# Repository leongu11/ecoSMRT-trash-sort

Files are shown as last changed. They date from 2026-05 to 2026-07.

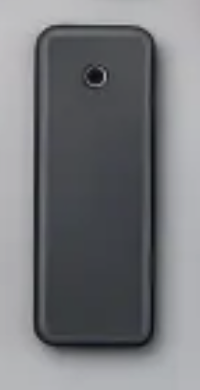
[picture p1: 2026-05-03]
SMRTcan-dataset/nonrecycling/box.jpg

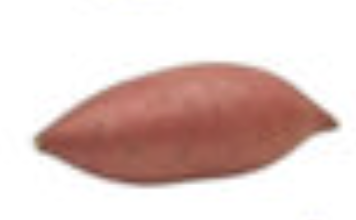
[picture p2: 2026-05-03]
SMRTcan-dataset/nonrecycling/fart.jpg

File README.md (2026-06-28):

github-header-banner

# ecoSMRT



## Overview
(this is my second README for this project -- I accidentally deleted the first one)
ecoSMRT is an edge AI project which determines if an article of trash is a recyclable (bottle) or not and sorts it accordingly.
It uses a refined version of MobileNetV2's CNN (convolutional neural networks) specifically for this task to make quality inferences. The model is around 60-70% accuracy when it comes to strong confidences over the 90% threshold.
I have logged nearly 45+ hours working on ecoSMRT as part of Hackclub's program, STASIS. Journal entries after every work session are also posted on the repository. 

## Incentive
Often times, managing waste can be overwhelming and done incorrectly. At the recycling level, nearly 76% of recyclables are lost at the household level (https://recyclingpartnership.org/residential-recycling-report/), and even those which are put into the recycling bin can be wrongly classified. As these wrongly-sorted articles of trash add up, the recycling process loses its efficiency, inflating unnecessary costs to over $3.5 billion yearly for the US (https://www.federalrecycling.com/industry-insights/common-recycling-mistakes-and-how-to-avoid-them/). As a direct result, recycling becomes more of a burden than a tool. Human error is exacerbating what recycling aims to fix: bettering the environment. Instead of looking towards refining the system, we should look to fix the root of the cause, our inaccuracies, by removing ourselves from the equation. AI is better than humans probably so like make a trash sorter ig 🤷‍♂️.

## Assembly Instructions
Use .stl files to print all 3d parts -- this includes the lid, the two edge mount pieces, the servo-lid adapter piece, and the camera mount (which is fixed to one of the edge mounts). NOTE: THE SERVO-LID ADAPTER PIECE REQUIRES A PAUSE IN THE PRINT TO SNAP ON THE HORN IN ORDER TO SEAL IT INSIDE THE PRINT! Slide the lid between the mounts to fix it in the center of the bin. Fasten the servo to the edge mount with two servo horn screws (which should have come with the servo) and connect the servo-lid adapter with the horn inside to the servo. Connect the adapter and the lid's extensions together-- glue is reccomended. The lid should now not rotate freely and rotating it should turn the servo, too. Attach a usb-c to usb-c onto the esp32 and camera and tape/glue to the top of the mount, allowing the camera to rest on the side of the mount. Connect the usb-c and flash the test-camera sketch onto the Xiao. It should return an IP to visit on the web to check the positioning of the camera. Adjust accordingly in order to have a clear view of the center of the bin. Using three jumper wires, solder the ends to both a capacitor and diode (optional, but recommended) using the schematic as a guide. Connect these jumpers to the servo, matching the power, ground, and signal accordingly. Once complete, flash the ecoSMRT-code onto the xiao. You should see inferences in the serial monitor and the lid rotating when those inferences pass the .95 -- or 95% -- threshold. Use the usb-c to power with any wall plug adapter or even laptop. 

## How ecoSMRT was made
I had originally settled for a more complex mechanical sorter, but the AI proved to be a challenge, so I simplified its design down to focus on firmware. The AI and curating a dataset which could yield decent results was also hard: At first, I was taking pre-existing datasets online, but the models were terrible. I did a lot of research and realized that I should probably use the native camera and setup for the training data, which turned out to work much better. Also, I switched from FOMO to MobileNet because like a month in I realized that image detection and classification were completely different (explanation found in journal). Everything else was relatively smooth sailing.

## Bill of Materials
| Component | Description | Cost | Link | 
|---|---|---|---|
| XIAO ESP32S3 Sense | Microcontroller with camera | $23.99 | [link](https://www.amazon.com/gp/product/B0CNL755KP/ref=ox_sc_act_title_2?smid=A2QTZX14X1D97I&th=1)
| MG90 servo | Sorting | $8.88 | [link](https://www.amazon.com/Seeed-Studio-XIAO-ESP32-Sense/dp/B0C69FFVHH?th=1)
## Hardware 
- MCU - Xiao ESP32S3-Sense w/ built-in camera module:
The Xiao ESP32 felt like the suitable choice because of its dual-core processors and built-in camera, which allowed the classification model to run smoothly locally, along with its GPIO capabilities.
Camera - OV2640 
- MG90 Microservo:
I have had my fair share of bad experience with the SG90 on multiple accounts, so I opted for its counterpart with metal-geared teeth, which seemed to be a good idea for tourque.

## Electronic Framework
I designed a schematic and PCB for this project in KiCAD

Schematic for wiring on perfboard:



PCB: 




I plan to use a perfboard using these as references for the physical project. 

## CAD / 3d Printed Parts
SMRTCAN--exploded2

Parts are printed in PLA, amounting to around 300 grams of filament (although all my prototypes summed up to a kg spool)
These consist of the bin's lid, which revolves on small axis extensions. These pass through bores that connect to the edges of the lid, and, when connected to the servo, keep the lid at the set position. The mount for the ESP32 slides around the servo's housing and attach to its walls. Additionally, I have modeled small attachments to connect the two halves of the lid if it cannot be printed as one part. 

## Software & Dependencies
- Arduino IDE
- Edge Impulse CLI
- ESP32 Arduino Core 2.0.8+
- `bottleclassifications_inferencing` (included in `/lib`) (refined w/ Edge Impulse)
- servo/webserver libraries used for testing/deployment
  
here are some crappy inferences from my first few models:



### Image Classification VS Object Detection (written in a journal entry)
Classification observes the image as a whole and returns a confidence score; its only question to ask is: What is this thing in front of me? Detection has to decide three things: Are there multiple objects? What are the objects? Where are the objects? In this case, the model has to consider spatial data when moving forwards for its confidence, which takes a lot more computing power and is way too overkill for my project.

### How Image Classification Works
Image classification is tuning a pre-trained model for a specific need. My model, MobileNetV2 has already been trained on ImageNet with millions of classification data – its weights have already adjusted to finding curves, textures, and colors within an image. What the refining does is simply re-run these weights over the image (or vector with the image data) – there is a series of these filters (matricies which are averaged out to make smaller maps) that alter the feature map that compound on one another, so they take the last feature’s map, instead of the old image. In this way the filters are able to distinguish curves, then textures, then shapes, then the image itself – again stacking over itself. The result is a confidence score that can be achieved even with little data.

## Dataset
- Trained on [Edge Impulse](https://edgeimpulse.com)

## How It Works & Usage
Frames are fed into the CNN, which returns inferences for classifications in real time. If an inference exceeds the 90% confidence threshold, the servo adjusts lid in one direction or another, 'sorting' the article of trash. 

To use, place the trash on the lid in front of the camera and in any orientation and wait for the bin to sort before placing the second article of trash down. 

## Future Improvements
- Improving vision model by manually training on pytorch or by expanding dataset
- adding feet to the bin to stabilize and prevent shaking from disturbing classifications 💀
- adaptability

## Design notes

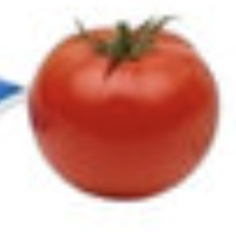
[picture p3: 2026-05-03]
SMRTcan-dataset/nonrecycling/ahah.jpg

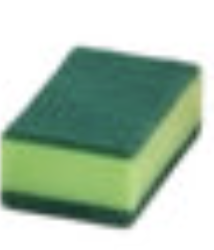
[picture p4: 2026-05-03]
SMRTcan-dataset/nonrecycling/ahhh.jpg

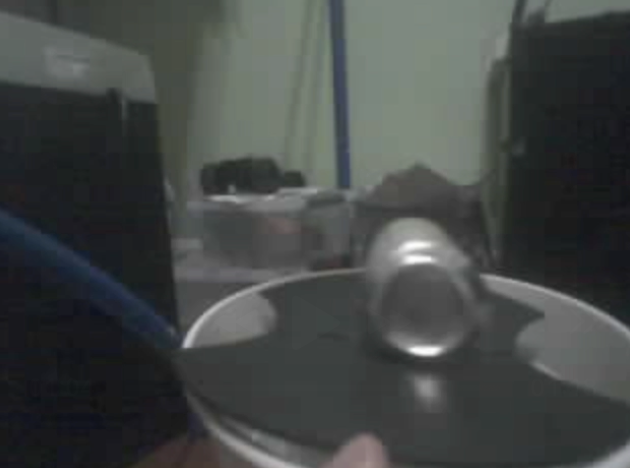
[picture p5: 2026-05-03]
SMRTcan-dataset/recycling/extra8.jpg

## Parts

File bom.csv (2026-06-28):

Component | Description | Cost | Link
XIAO ESP32S3 Sense | Microcontroller with camera | $23.99 | link
MG90 servo | Sorting | $8.88 | link

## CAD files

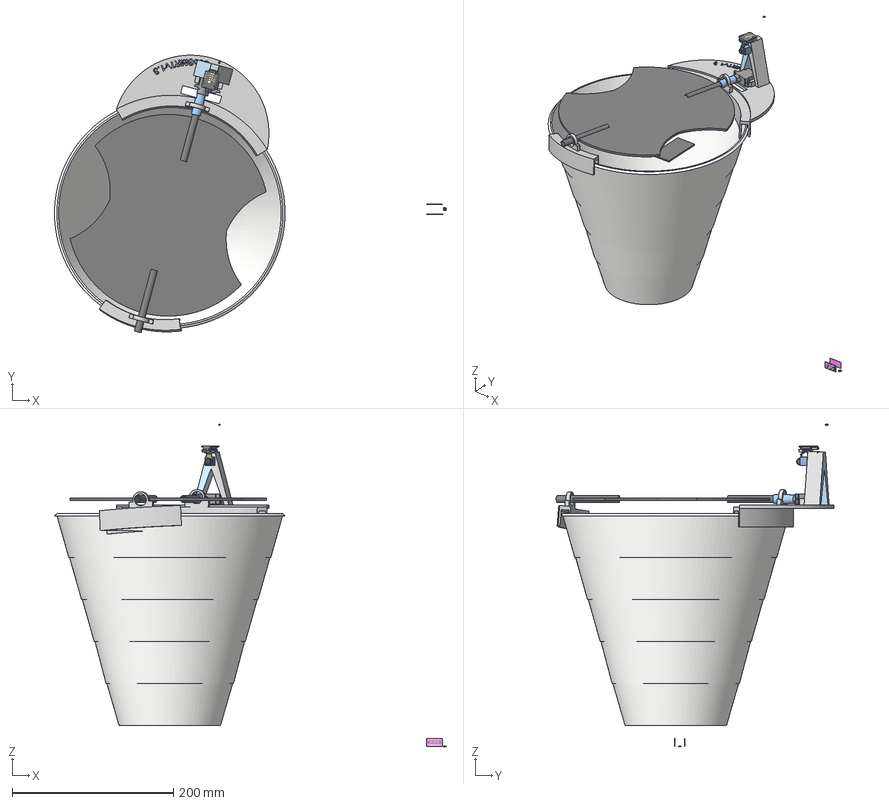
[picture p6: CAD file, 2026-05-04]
CAD/3mfs/ecoSMRT_full-assembly2.3mf
486.1 x 344.3 x 400.3 mm
M
adapter
p1 (2)

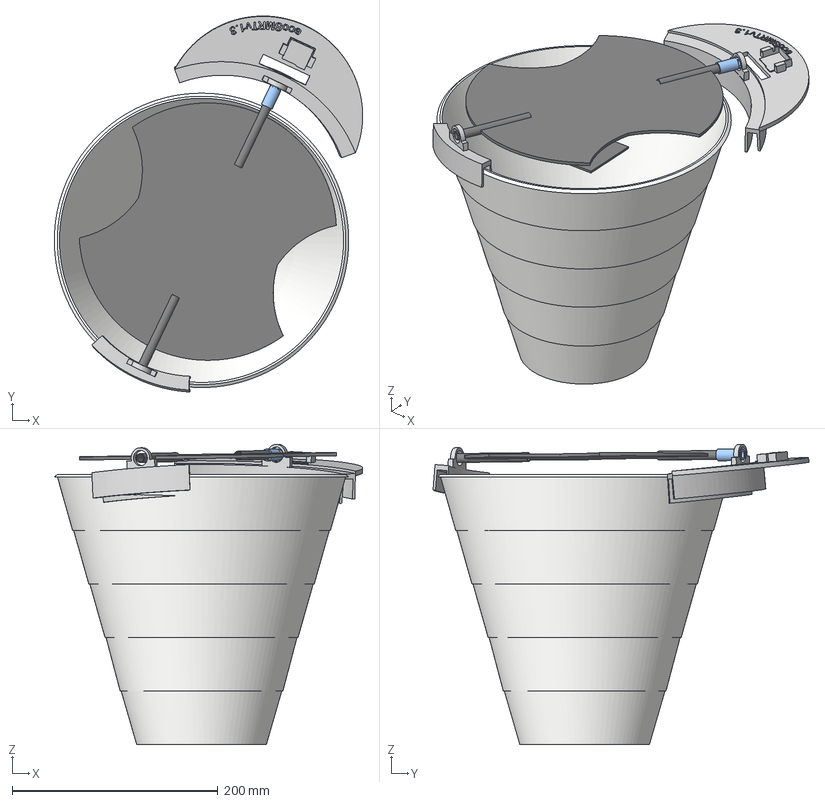
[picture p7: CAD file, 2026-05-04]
CAD/3mfs/ecoSMRT-can_full-assembly.3mf
299.5 x 365.2 x 291.7 mm
M
adapter
p1 (2)

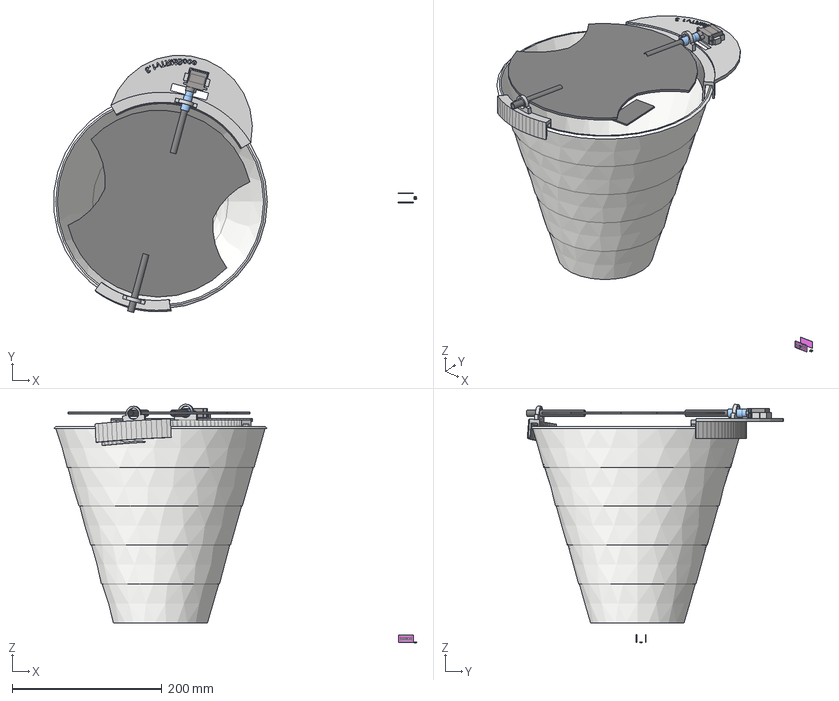
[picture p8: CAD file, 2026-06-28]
CAD/step/SMRTCAN.step
485.4 x 343.9 x 319.1 mm
axe
base001
etiquette
Tube
Cylindre
Tube001
Tube002
etiquette001
Cylindre001
Cylindre002

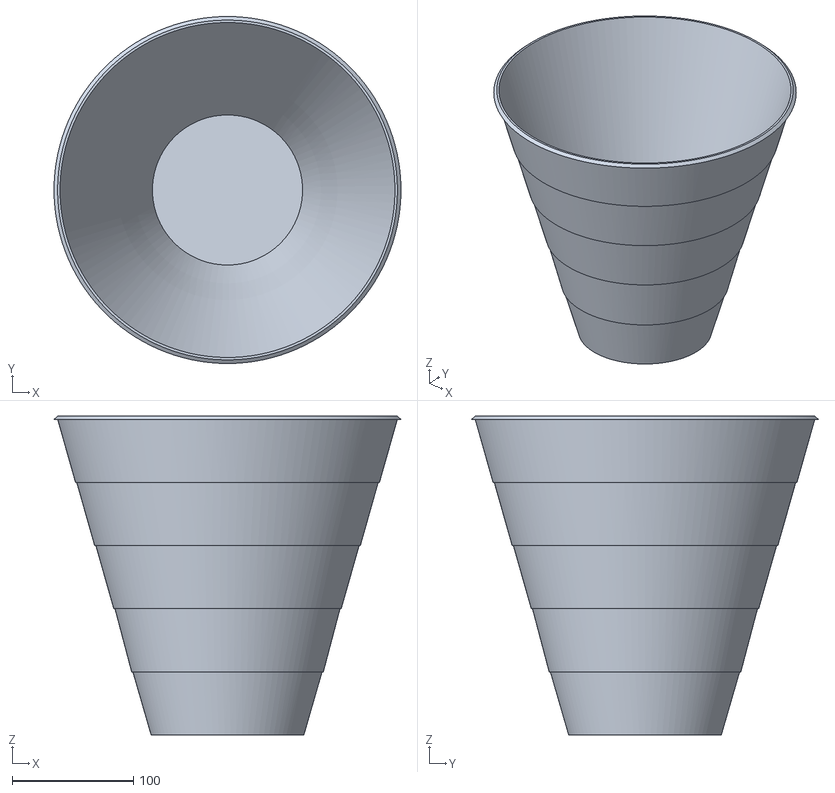
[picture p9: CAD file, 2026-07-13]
CAD/stls/ecosmrt-final-bin.stl
285.9 x 285.9 x 262.6

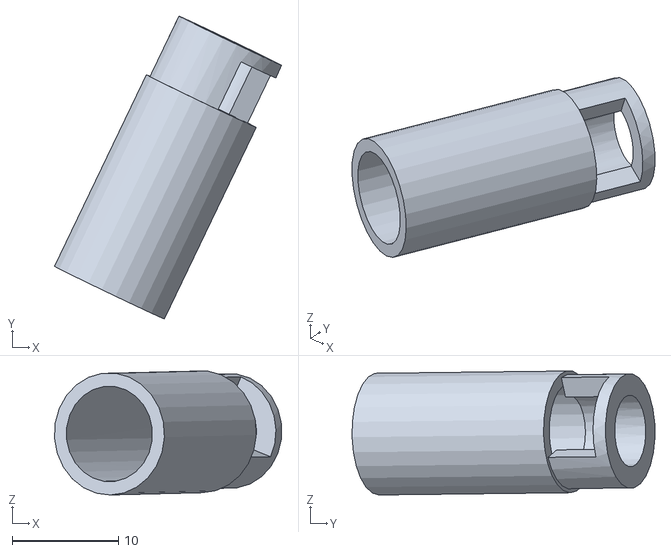
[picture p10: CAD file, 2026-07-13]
CAD/stls/ecosmrt-final-adapter.stl
21.4 x 28.5 x 11.7

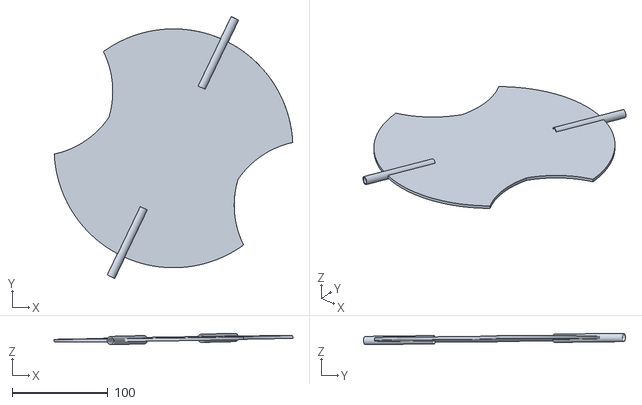
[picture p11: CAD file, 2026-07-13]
CAD/stls/ecosmrt-final-lid.stl
249.7 x 274.3 x 11.9

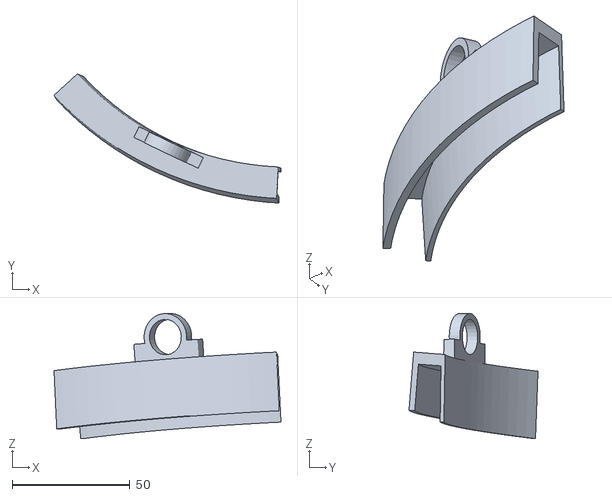
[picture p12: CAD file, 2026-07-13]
CAD/stls/ecosmrt-final-edgesmall.stl
96.2 x 54.7 x 53.1

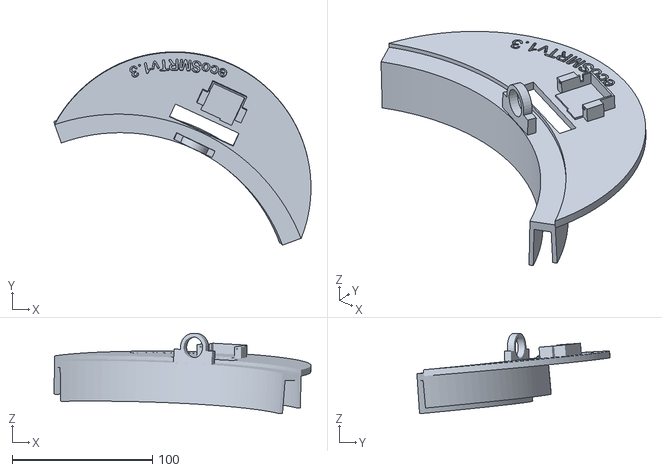
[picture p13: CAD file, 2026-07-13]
CAD/stls/ecosmrt-final-edge.stl
183.0 x 137.7 x 57.2

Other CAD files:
CAD/stls/SMRTCAN.stl

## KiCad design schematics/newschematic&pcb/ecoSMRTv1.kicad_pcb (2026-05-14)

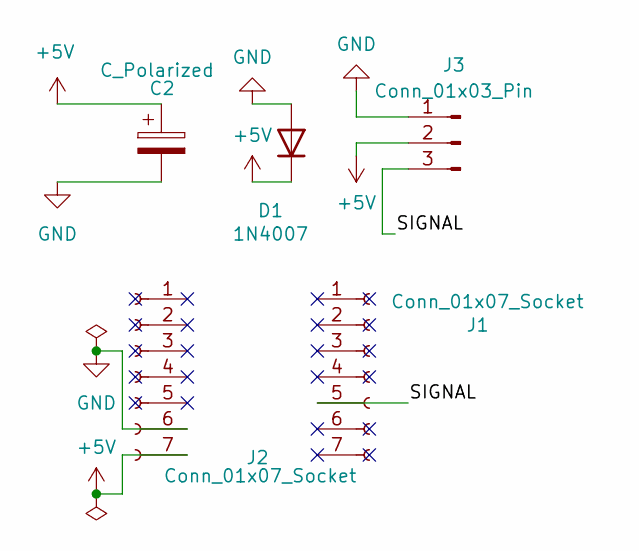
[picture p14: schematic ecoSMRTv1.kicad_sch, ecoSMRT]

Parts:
C2: C_Polarized; C_Radial_D5.0mm_H11.0mm_P2.00mm
D1: 1N4007; D_DO-41_SOD81_P10.16mm_Horizontal
J1, J2: Conn_01x07_Socket; PinSocket_1x07_P2.54mm_Vertical_SMD_Pin1Right
J3: Conn_01x03_Pin; PinHeader_1x03_P2.54mm_Vertical

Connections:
+5V: C2.1, D1.1 (K), J2.7, J3.2
/SIGNAL: J1.5 (Pin_5_5), J3.3
GND: C2.2, D1.2 (A), J2.6, J3.1

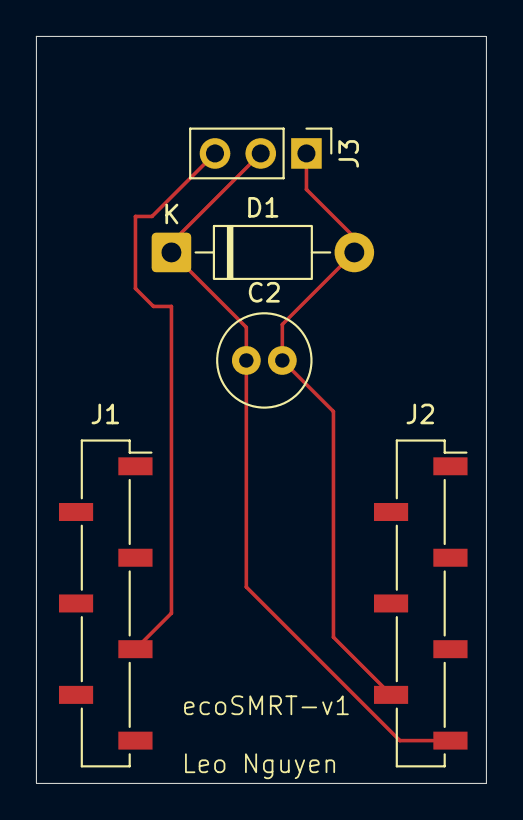
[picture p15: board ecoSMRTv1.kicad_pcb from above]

Board: 2 copper layers, 25.0 x 41.5 mm, 5 parts (0 on the bottom side), 3 nets.

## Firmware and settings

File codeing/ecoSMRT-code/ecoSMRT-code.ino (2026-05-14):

/* Edge Impulse Arduino examples
 * Copyright (c) 2022 EdgeImpulse Inc.
 * Modified for XIAO ESP32S3 Sense
 */

#include <bottleclassifications_inferencing.h>
#include "edge-impulse-sdk/dsp/image/image.hpp"
#include "esp_camera.h"
#include <ESP32Servo.h>

// XIAO ESP32S3 Sense camera pins
Servo lidServo;
#define PWDN_GPIO_NUM     -1
#define RESET_GPIO_NUM    -1
#define XCLK_GPIO_NUM     10
#define SIOD_GPIO_NUM     40
#define SIOC_GPIO_NUM     39

#define Y9_GPIO_NUM       48
#define Y8_GPIO_NUM       11
#define Y7_GPIO_NUM       12
#define Y6_GPIO_NUM       14
#define Y5_GPIO_NUM       16
#define Y4_GPIO_NUM       18
#define Y3_GPIO_NUM       17
#define Y2_GPIO_NUM       15
#define VSYNC_GPIO_NUM    38
#define HREF_GPIO_NUM     47
#define PCLK_GPIO_NUM     13

/* Constant defines -------------------------------------------------------- */
#define EI_CAMERA_RAW_FRAME_BUFFER_COLS           320
#define EI_CAMERA_RAW_FRAME_BUFFER_ROWS           240
#define EI_CAMERA_FRAME_BYTE_SIZE                 3

/* Private variables ------------------------------------------------------- */
static bool debug_nn = false;
static bool is_initialised = false;
uint8_t *snapshot_buf;

static camera_config_t camera_config = {
    .pin_pwdn = PWDN_GPIO_NUM,
    .pin_reset = RESET_GPIO_NUM,
    .pin_xclk = XCLK_GPIO_NUM,
    .pin_sscb_sda = SIOD_GPIO_NUM,
    .pin_sscb_scl = SIOC_GPIO_NUM,

    .pin_d7 = Y9_GPIO_NUM,
    .pin_d6 = Y8_GPIO_NUM,
    .pin_d5 = Y7_GPIO_NUM,
    .pin_d4 = Y6_GPIO_NUM,
    .pin_d3 = Y5_GPIO_NUM,
    .pin_d2 = Y4_GPIO_NUM,
    .pin_d1 = Y3_GPIO_NUM,
    .pin_d0 = Y2_GPIO_NUM,
    .pin_vsync = VSYNC_GPIO_NUM,
    .pin_href = HREF_GPIO_NUM,
    .pin_pclk = PCLK_GPIO_NUM,

    .xclk_freq_hz = 20000000,
    .ledc_timer = LEDC_TIMER_0,
    .ledc_channel = LEDC_CHANNEL_0,

    .pixel_format = PIXFORMAT_JPEG,
    .frame_size = FRAMESIZE_QVGA,

    .jpeg_quality = 12,
    .fb_count = 1,
    .fb_location = CAMERA_FB_IN_PSRAM,
    .grab_mode = CAMERA_GRAB_WHEN_EMPTY,
};

/* Function declarations */
bool ei_camera_init(void);
void ei_camera_deinit(void);
bool ei_camera_capture(uint32_t img_width, uint32_t img_height, uint8_t *out_buf);
static int ei_camera_get_data(size_t offset, size_t length, float *out_ptr);

/* Setup */
void setup()
{
    Serial.begin(115200);
    while (!Serial);

    lidServo.attach(3);

    Serial.println("Edge Impulse Inferencing Demo - XIAO ESP32S3 Sense");

    if (ei_camera_init() == false) {
        ei_printf("Failed to initialize Camera!\r\n");
    } else {
        ei_printf("Camera initialized\r\n");
    }

    ei_printf("\nStarting continuous inference in 2 seconds...\n");
    ei_sleep(2000);
}

/* Loop */
void loop()
{
    if (ei_sleep(5) != EI_IMPULSE_OK) {
        return;
    }

    snapshot_buf = (uint8_t*)malloc(EI_CAMERA_RAW_FRAME_BUFFER_COLS * EI_CAMERA_RAW_FRAME_BUFFER_ROWS * EI_CAMERA_FRAME_BYTE_SIZE);

    if (snapshot_buf == nullptr) {
        ei_printf("ERR: Failed to allocate snapshot buffer!\n");
        return;
    }

    ei::signal_t signal;
    signal.total_length = EI_CLASSIFIER_INPUT_WIDTH * EI_CLASSIFIER_INPUT_HEIGHT;
    signal.get_data = &ei_camera_get_data;

    if (ei_camera_capture((size_t)EI_CLASSIFIER_INPUT_WIDTH, (size_t)EI_CLASSIFIER_INPUT_HEIGHT, snapshot_buf) == false) {
        ei_printf("Failed to capture image\r\n");
        free(snapshot_buf);
        return;
    }

    ei_impulse_result_t result = { 0 };

    EI_IMPULSE_ERROR err = run_classifier(&signal, &result, debug_nn);
    if (err != EI_IMPULSE_OK) {
        ei_printf("ERR: Failed to run classifier (%d)\n", err);
        free(snapshot_buf);
        return;
    }

    ei_printf("Predictions (DSP: %d ms., Classification: %d ms., Anomaly: %d ms.): \n",
                result.timing.dsp, result.timing.classification, result.timing.anomaly);

#if EI_CLASSIFIER_OBJECT_DETECTION == 1
    ei_printf("Object detection bounding boxes:\r\n");
    for (uint32_t i = 0; i < result.bounding_boxes_count; i++) {
        ei_impulse_result_bounding_box_t bb = result.bounding_boxes[i];
        if (bb.value == 0) continue;
        ei_printf("  %s (%f) [ x: %u, y: %u, width: %u, height: %u ]\r\n",
                bb.label, bb.value, bb.x, bb.y, bb.width, bb.height);
    }
#else
    float max_value = 0;
    const char* max_label = "";

    ei_printf("Predictions:\r\n");
    for (uint16_t i = 0; i < EI_CLASSIFIER_LABEL_COUNT; i++) {
        ei_printf("  %s: ", ei_classifier_inferencing_categories[i]);
        ei_printf("%.5f\r\n", result.classification[i].value);
        //ONLY best most confident guess
        if (result.classification[i].value > max_value) {
            max_value = result.classification[i].value;
            max_label = ei_classifier_inferencing_categories[i];
        }
    }

    ei_printf("Best prediction: %s (%.5f)\r\n", max_label, max_value);

    if (strcmp(max_label, "bottle") == 0 && max_value > 0.9) {
        ei_printf("Bottle detected!\r\n");
        // pray for ts  
        lidServo.write(0);  // open
        delay(3000);
        lidServo.write(80);  // start closed
    }
    if (strcmp(max_label, "notbottle") == 0 && max_value > 0.7) {
        ei_printf("not Bottle detected!\r\n");
        // pray for ts  
        lidServo.write(160);  // open
        delay(3000);
        lidServo.write(80);  // start closed
    }
#endif

#if EI_CLASSIFIER_HAS_ANOMALY
    ei_printf("Anomaly prediction: %.3f\r\n", result.anomaly);
#endif

#if EI_CLASSIFIER_HAS_VISUAL_ANOMALY
    ei_printf("Visual anomalies:\r\n");
    for (uint32_t i = 0; i < result.visual_ad_count; i++) {
        ei_impulse_result_bounding_box_t bb = result.visual_ad_grid_cells[i];
        if (bb.value == 0) continue;
        ei_printf("  %s (%f) [ x: %u, y: %u, width: %u, height: %u ]\r\n",
                bb.label, bb.value, bb.x, bb.y, bb.width, bb.height);
    }
#endif

    free(snapshot_buf);
}

/* Camera functions */
bool ei_camera_init(void) {
    if (is_initialised) return true;

    esp_err_t err = esp_camera_init(&camera_config);
    if (err != ESP_OK) {
        Serial.printf("Camera init failed with error 0x%x\n", err);
        return false;
    }

    sensor_t *s = esp_camera_sensor_get();
    s->set_vflip(s, 1);
    s->set_hmirror(s, 0);

    is_initialised = true;
    return true;
}

void ei_camera_deinit(void) {
    esp_err_t err = esp_camera_deinit();
    if (err != ESP_OK) {
        ei_printf("Camera deinit failed\n");
        return;
    }
    is_initialised = false;
}

bool ei_camera_capture(uint32_t img_width, uint32_t img_height, uint8_t *out_buf) {
    bool do_resize = false;

    if (!is_initialised) {
        ei_printf("ERR: Camera is not initialized\r\n");
        return false;
    }

    camera_fb_t *fb = esp_camera_fb_get();
    if (!fb) {
        ei_printf("Camera capture failed\n");
        return false;
    }

    bool converted = fmt2rgb888(fb->buf, fb->len, PIXFORMAT_JPEG, snapshot_buf);
    esp_camera_fb_return(fb);

    if (!converted) {
        ei_printf("Conversion failed\n");
        return false;
    }

    if ((img_width != EI_CAMERA_RAW_FRAME_BUFFER_COLS)
        || (img_height != EI_CAMERA_RAW_FRAME_BUFFER_ROWS)) {
        do_resize = true;
    }

    if (do_resize) {
        ei::image::processing::crop_and_interpolate_rgb888(
            out_buf,
            EI_CAMERA_RAW_FRAME_BUFFER_COLS,
            EI_CAMERA_RAW_FRAME_BUFFER_ROWS,
            out_buf,
            img_width,
            img_height);
    }

    return true;
}

static int ei_camera_get_data(size_t offset, size_t length, float *out_ptr)
{
    size_t pixel_ix = offset * 3;
    size_t pixels_left = length;
    size_t out_ptr_ix = 0;

    while (pixels_left != 0) {
        out_ptr[out_ptr_ix] = (snapshot_buf[pixel_ix + 2] << 16) + (snapshot_buf[pixel_ix + 1] << 8) + snapshot_buf[pixel_ix];
        out_ptr_ix++;
        pixel_ix += 3;
        pixels_left--;
    }
    return 0;
}

#if !defined(EI_CLASSIFIER_SENSOR) || EI_CLASSIFIER_SENSOR != EI_CLASSIFIER_SENSOR_CAMERA
#error "Invalid model for current sensor"
#endif

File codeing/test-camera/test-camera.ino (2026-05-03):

#include "esp_camera.h"
#include <WiFi.h>
#include <WebServer.h>

// these are pins given on the xiao for the camera -- built-in basically from the interwebs

#define PWDN_GPIO_NUM  -1
#define RESET_GPIO_NUM -1
#define XCLK_GPIO_NUM  10
#define SIOD_GPIO_NUM  40
#define SIOC_GPIO_NUM  39

#define Y9_GPIO_NUM    48
#define Y8_GPIO_NUM    11
#define Y7_GPIO_NUM    12
#define Y6_GPIO_NUM    14
#define Y5_GPIO_NUM    16
#define Y4_GPIO_NUM    18
#define Y3_GPIO_NUM    17
#define Y2_GPIO_NUM    15
#define VSYNC_GPIO_NUM 38
#define HREF_GPIO_NUM  47
#define PCLK_GPIO_NUM  13

//start websocket to share feed
WebServer server(80);
camera_config_t config;

void handleCamera() {
  config.ledc_channel = LEDC_CHANNEL_0;
  config.ledc_timer = LEDC_TIMER_0;

  config.pin_d0 = Y2_GPIO_NUM;
  config.pin_d1 = Y3_GPIO_NUM;
  config.pin_d2 = Y4_GPIO_NUM;
  config.pin_d3 = Y5_GPIO_NUM;
  config.pin_d4 = Y6_GPIO_NUM;
  config.pin_d5 = Y7_GPIO_NUM;
  config.pin_d6 = Y8_GPIO_NUM;
  config.pin_d7 = Y9_GPIO_NUM;

  config.pin_xclk = XCLK_GPIO_NUM;
  config.pin_pclk = PCLK_GPIO_NUM;
  config.pin_vsync = VSYNC_GPIO_NUM;
  config.pin_href = HREF_GPIO_NUM;

  config.pin_sscb_sda = SIOD_GPIO_NUM;
  config.pin_sscb_scl = SIOC_GPIO_NUM;

  config.pin_pwdn = PWDN_GPIO_NUM;
  config.pin_reset = RESET_GPIO_NUM;

  config.xclk_freq_hz = 20000000;
  config.pixel_format = PIXFORMAT_JPEG;
  config.frame_size = FRAMESIZE_QVGA;
  config.jpeg_quality = 12;
  config.fb_count = 1;
  config.fb_location  = CAMERA_FB_IN_PSRAM;

}

void handleStream() {
    server.setContentLength(CONTENT_LENGTH_UNKNOWN);
    server.send(200, "multipart/x-mixed-replace; boundary=frame", "");

    char header[64];

    while (true) {
        camera_fb_t *fb = esp_camera_fb_get();
        if (!fb) continue;

        snprintf(header, sizeof(header),
            "--frame\r\nContent-Type: image/jpeg\r\nContent-Length: %u\r\n\r\n",
            fb->len);

        server.sendContent(header);
        server.sendContent((char*)fb->buf, fb->len);
        server.sendContent("\r\n");

        esp_camera_fb_return(fb);
        delay(33);
    }
}

void setup() {
  Serial.begin(115200);   

  //remember to change before committing
  WiFi.mode(WIFI_STA);
  WiFi.setSleep(false);
  WiFi.disconnect();
  delay(1000);  // longer delay
  WiFi.begin("Daddy iPhone", "Nguyen2941");

  int attempts = 0;
  while (WiFi.status() != WL_CONNECTED && attempts < 60) {
      delay(1000);  // longer between attempts
      attempts++;
      Serial.print("Attempt ");
      Serial.print(attempts);
      Serial.print(" status: ");
      Serial.println(WiFi.status());
  }

  Serial.println(WiFi.localIP());
  server.on("/",handleStream);
  server.begin();

  handleCamera();

  if (esp_camera_init(&config) != ESP_OK) {
    Serial.println("camera doesnt start");
    return;
  } 
  Serial.println("camera success");
}

void loop() {
  server.handleClient();
}

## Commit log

2026-05-03 project design over-- finished firmware finally
    [testkicad.kicad_sch]
2026-05-04 added cad files
    [ecoSMRT-can_full-assembly.3mf]
2026-05-04 updated assembly w/electronic components included
    [ecoSMRT_full-assembly2.3mf]
2026-05-13 Enhance README with additional project details
    Added sections on electronic framework, CAD parts, and software dependencies. Updated incentive and how ecoSMRT was made sections for clarity.
2026-05-14 new schematics and new PCB
    [ecoSMRTv1.kicad_pcb, ecoSMRTv1.kicad_sch, testkicad.kicad_pcb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]
2026-05-14 new pcb and schems
2026-06-07 gerber files
    [ecoSMRTv1-B_Cu.gbr, ecoSMRTv1-B_Mask.gbr, ecoSMRTv1-B_Paste.gbr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]
2026-06-28 new files redone and assembly instructions in readme
    [SMRTCAN.step, SMRTCAN.stl, ecoSMRT-can_full-assembly.3mf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]
2026-07-13 readded gerbers which deleted for some reason
    [ecoSMRTv1-B_Cu.gbr, ecoSMRTv1-B_Mask.gbr, ecoSMRTv1-B_Paste.gbr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]
2026-07-13 moved into folder
    [ecoSMRTv1-B_Mask.gbr, ecoSMRTv1-B_Paste.gbr, ecoSMRTv1-B_Silkscreen.gbr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]
